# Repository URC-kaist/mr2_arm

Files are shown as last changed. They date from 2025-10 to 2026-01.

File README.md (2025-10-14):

# MR2 Arm Firmware

Firmware targeting the STM32H523 MCU that supervises two AS5600 magnetic encoders, a limit switch polled on GPIOA1, and broadcasts system state over classic CAN (FDCAN1). The code lives under `Core/Src/main.c` and is generated from STM32CubeMX, with custom logic in the `USER CODE` sections.

## High-Level Flow
- System clock configured to run from the CSI oscillator via PLL1 (SYSCLK ≈ 250 MHz).
- GPIO, I2C1/I2C2, ICACHE, FDCAN1, USART2, and TIM1 peripherals are initialized.
- FDCAN1 is started in normal classic-CAN mode and ready to transmit.
- TIM1 runs as a 10 Hz scheduler (prescaler 24 999, period 999). Its update interrupt raises `angle_check_pending` to request an encoder refresh.
- TIM2 runs as a 500 Hz poller for the limit switch and queues CAN updates.
- The main loop services queued limit-switch CAN events, executes encoder refresh work when requested, and idles via `__WFI()` when nothing is pending.

## Sensors and Peripherals

### AS5600 Encoders (I2C1 / I2C2)
- Each bus targets an AS5600 at 0x36 (7-bit address). Reads use `HAL_I2C_Mem_Read` from register `0x0E` (`ANGLE`).
- `AngleCheck_Run()` pulls the 12-bit angle from both sensors. Conversion to degrees is purely for UART logging; the broadcast value is kept in counts.
- Data is shifted to signed Q24 centered around mid-scale (`(angle - 2048) << 12`) and saturated to the ±24-bit range before being queued for CAN transmission.
- Each encoder publishes its own CAN frame (IDs `0x180` and `0x182` respectively); payload layout is detailed below.
- Encoder status flags track:
  - `bit0` (`ENC_FLAG_INDEX_SEEN`): at least one valid read has occurred.
  - `bit1` (`ENC_FLAG_ERROR_LATCHED`): a fault has been observed and latched.
  - `bit2` (`ENC_FLAG_SENSOR_FAULT`): latest read failed (cleared on the next good sample).
  - `bit3` (`ENC_FLAG_OVER_SPEED`): reserved for future use; never set in current code.
- I2C faults are logged to USART2 at 115 200 baud. After two consecutive failures the firmware attempts a soft bus recovery (deinit/re-init plus filter restore) before retrying the read once.

### Limit Switch (GPIOA Pin 1 / TIM2 sampled)
- TIM2 runs at 500 Hz in interrupt mode. Its period callback samples the GPIO and detects edges.
- The most recent state is broadcast immediately on any change and again every 200 ms (5 Hz) even if the level is unchanged.
- The timer ISR only prepares the CAN payload; the main loop performs the actual transmit when the TX FIFO has room.

### Scheduler (TIM1)
- With the configured prescaler and period, TIM1 Update fires every 100 ms.
- The callback increments `angle_check_pending`, allowing the main loop to run encoder polling at ~10 Hz.
- The initial call to `AngleCheck_Run()` ensures the encoders are read immediately after boot before the first timer tick.

### Serial Debug (USART2)
- Simple TX-only logging via `UART_SendLine()` for probe results and angle readouts.

## CAN Interface
Classic CAN (FDCAN1), 11-bit standard IDs, FD features disabled, no CRC inside the payloads (CAN handles CRC).

### 0x180 — Encoder 1 Status (sent every encoder poll)
| Bytes | Description |
|---|---|
| 0-2 | Encoder 1 position, signed Q24 big-endian (`PackS24BE`) |
| 3 | Encoder 1 status flags (`bit0 index_seen`, `bit1 error_latched`, `bit2 sensor_fault`, `bit3 over_speed`, others reserved) |
| 4-7 | Reserved (set to 0) |

### 0x182 — Encoder 2 Status (sent every encoder poll)
| Bytes | Description |
|---|---|
| 0-2 | Encoder 2 position, signed Q24 big-endian (`PackS24BE`) |
| 3 | Encoder 2 status flags (`bit0 index_seen`, `bit1 error_latched`, `bit2 sensor_fault`, `bit3 over_speed`, others reserved) |
| 4-7 | Reserved (set to 0) |

Notes (apply to both encoder status frames):
- Positions wrap naturally with the signed Q24 representation; receivers should apply their own counts-to-angle scaling using 4 096 counts per revolution.
- Fault bits remain latched until firmware reset; `sensor_fault` clears automatically on a good read.
- Although the code currently polls at 10 Hz, adjust `TIM1` prescaler/period if you require a 100 Hz cadence (update the README accordingly if you change it).

### 0x181 — Limit Switch State (5 Hz periodic, immediate on change)
| Bytes | Description |
|---|---|
| 0 | Switch state (`0` released, `1` pressed) |
| 1-7 | Reserved (set to 0) |

Notes:
- TIM2-driven sampling ensures new levels are observed within 2 ms. The firmware queues an out-of-band frame as soon as a change is detected, then resumes the 5 Hz cadence from that point.
- Frames are queued from the timer callback and emitted in the main loop; if the TX FIFO is full the entry is retried on the next pass.

## Extending the Firmware
- To add more diagnostics to CAN, reuse the helper `CAN_SendFrame()` and extend the payload tables above.
- Modify the `encoder_status_flags` logic to reflect any additional alarm conditions (e.g., overspeed detection) and document the bits here.
- If you retune the scheduler or switch to asynchronous encoder reads, ensure `LimitSwitch_Service()` still runs frequently enough to flush pending frames.

For detailed implementation, consult `Core/Src/main.c` (line numbers referenced above). Update this README whenever payload definitions or scheduling behavior change.

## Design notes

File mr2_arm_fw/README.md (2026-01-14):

# MR2 Arm Firmware

Firmware targeting the STM32H523 MCU that supervises two AS5600 magnetic encoders, dual-channel limit switches on GPIOA4–GPIOA7, and broadcasts system state over classic CAN (FDCAN1). CubeMX still owns the peripheral scaffolding in `Core/Src/main.c`, while the application logic now lives in:
- `Core/Src/app_encoder.c` — encoder sampling, I2C fault handling, and encoder CAN framing.
- `Core/Src/app_limit_switch.c` — limit switch polling, fault detection, and CAN framing.
- `Core/Src/app_can.c` — shared CAN helpers and bus-off recovery orchestration.
- `Core/Src/app_config.c` — holds runtime configuration that controls which
  channels are active and what CAN base ID to use.

## High-Level Flow
- System clock configured to run from the CSI oscillator via PLL1 (SYSCLK ≈ 250 MHz).
- GPIO, I2C1/I2C2, ICACHE, FDCAN1, USART2, and TIM1 peripherals are initialized.
- FDCAN1 is started in normal classic-CAN mode and ready to transmit.
- TIM1 runs as a 10 Hz scheduler (prescaler 24 999, period 999). Its update interrupt calls `AppEncoder_OnSchedulerTick()` to request a fresh encoder sample.
- TIM2 runs as a 500 Hz poller for the limit switches and invokes `AppLimitSwitch_Poll()` every tick.
- The main loop flushes queued limit-switch frames via `AppLimitSwitch_Service()`, performs encoder work via `AppEncoder_Service()`, services CAN bus-off recovery, and idles via `__WFI()` once nothing is pending.

## Sensors and Peripherals

### AS5600 Encoders (I2C1 / I2C2)
- Each bus targets an AS5600 at 0x36 (7-bit address). Reads use `HAL_I2C_Mem_Read` from register `0x0E` (`ANGLE`).
- `AppEncoder_Service()` performs the 12-bit angle read for both sensors when work is pending. Conversion to degrees is purely for UART logging; the broadcast value is kept in counts.
- Data is shifted to signed Q24 centered around mid-scale (`(angle - 2048) << 12`) and saturated to the ±24-bit range before being queued for CAN transmission.
- Each encoder publishes its own CAN frame (IDs `0x180` and `0x182` respectively); payload layout is detailed below.
- Encoder status flags track:
  - `bit0` (`ENC_FLAG_INDEX_SEEN`): at least one valid read has occurred.
  - `bit1` (`ENC_FLAG_ERROR_LATCHED`): a fault has been observed and latched.
  - `bit2` (`ENC_FLAG_SENSOR_FAULT`): latest read failed (cleared on the next good sample).
  - `bit3` (`ENC_FLAG_OVER_SPEED`): reserved for future use; never set in current code.
- I2C faults are logged to USART2 at 115 200 baud. After two consecutive failures the firmware attempts a soft bus recovery (deinit/re-init plus filter restore) before retrying the read once.

### Limit Switches (GPIOA Pins 4–7 / TIM2 sampled)
- SW1 and SW2 each provide normally-closed (NC) and normally-open (NO) contacts on pins `PA4`–`PA7`, sampled with `GPIO_PULLUP`.
- TIM2 runs at 500 Hz in interrupt mode. Its period callback reads all four contacts, detects changes, and records a change mask per switch via `AppLimitSwitch_Poll()`.
- For valid combinations (`NC=0, NO=1` = released, `NC=1, NO=0` = pressed) the firmware derives a binary state (`0` open, `1` closed) and clears the fault flag.
- Each switch publishes its status frame on its own CAN identifier immediately on any state or fault change, and otherwise every 200 ms (5 Hz) while the contacts remain valid.
- When an invalid combination is sampled (`NC == NO`), the frame's fault flag (`byte 1 bit 0`) is asserted and transmissions are rate-limited to once every 500 ms until the contacts return to a valid state (after which the cadence returns to 200 ms).
- The timer ISR only prepares the CAN payload; the main loop attempts the transmit in `AppLimitSwitch_Service()` when the TX FIFO has room.

### Scheduler (TIM1)
- With the configured prescaler and period, TIM1 Update fires every 100 ms.
- The callback defers to `AppEncoder_OnSchedulerTick()`, allowing the main loop to service encoder polling at ~10 Hz via `AppEncoder_Service()`.
- Startup logic requests and processes one encoder sample before the first timer tick so the CAN bus is primed immediately after boot.

### Debug Output (UART)
- `printf` is retargeted to `USART2` at 115 200 baud via `retarget.c`; all logs go out over that UART.

## CAN Interface
Classic CAN (FDCAN1), 11-bit standard IDs, FD features disabled, no CRC inside the payloads (CAN handles CRC).

### 0x180 — Encoder 1 Status (sent every encoder poll, 4-byte DLC)
| Bytes | Description |
|---|---|
| 0-2 | Encoder 1 position, signed Q24 big-endian (`PackS24BE`) |
| 3 | Encoder 1 status flags (`bit0 index_seen`, `bit1 error_latched`, `bit2 sensor_fault`, `bit3 over_speed`, others reserved) |

### 0x182 — Encoder 2 Status (sent every encoder poll, 4-byte DLC)
| Bytes | Description |
|---|---|
| 0-2 | Encoder 2 position, signed Q24 big-endian (`PackS24BE`) |
| 3 | Encoder 2 status flags (`bit0 index_seen`, `bit1 error_latched`, `bit2 sensor_fault`, `bit3 over_speed`, others reserved) |

Notes (apply to both encoder status frames):
- Positions wrap naturally with the signed Q24 representation; receivers should apply their own counts-to-angle scaling using 4 096 counts per revolution. With the reduced DLC, only bytes 0–3 are emitted (no padding).
- Fault bits remain latched until firmware reset; `sensor_fault` clears automatically on a good read.
- Although the code currently polls at 10 Hz, adjust `TIM1` prescaler/period if you require a 100 Hz cadence (update the README accordingly if you change it).

### 0x181 — Limit Switch 1 Status (SW1, immediate on change; 5 Hz valid / 0.5 s fault cadence, 2-byte DLC)
| Bytes | Description |
|---|---|
| 0 | Switch state (`0` open, `1` closed). When a fault is active the last known state is retained. |
| 1 | Fault bits (`bit0`=1 when NC/NO inputs disagree; other bits reserved 0). |

### 0x183 — Limit Switch 2 Status (SW2, immediate on change; 5 Hz valid / 0.5 s fault cadence, 2-byte DLC)
| Bytes | Description |
|---|---|
| 0 | Switch state (`0` open, `1` closed). When a fault is active the last known state is retained. |
| 1 | Fault bits (`bit0`=1 when NC/NO inputs disagree; other bits reserved 0). |

Notes:
- TIM2-driven sampling ensures new levels are observed within 2 ms. The firmware queues an out-of-band frame as soon as a state or fault change is detected.

- While the contacts remain valid, status frames repeat every 200 ms. When a fault persists, transmissions are throttled to once every 500 ms until the inputs recover.
- Frames are queued from the timer callback and emitted in the main loop; if the TX FIFO is full the latest payload is retried on the next pass.

### Runtime Configuration (`AppConfig`)
- The `AppConfig` struct enables or disables each sensor independently (`enable_sw1`, `enable_sw2`, `enable_encoder1`, `enable_encoder2`). Disabled channels neither sample hardware nor emit CAN frames.
- You can supply explicit 11-bit CAN IDs per channel via `can_id_encoder1`, `can_id_encoder2`, `can_id_sw1`, `can_id_sw2` (set to `0` to fall back to the base+offset scheme). All IDs must be ≤ `0x7FF`.
- If no per-channel ID is provided, `can_base_id` sets the starting standard ID for all status frames (default `0x180`). Offsets are fixed: encoder1 = `base+0`, SW1 = `base+1`, encoder2 = `base+2`, SW2 = `base+3`. `can_base_id` values above `0x7FC` are rejected to keep offsets within the 11-bit range.
- Defaults are applied in `main.c` via `AppConfig_InitDefaults()`/`AppConfig_Set()`, then pushed into the modules with `AppEncoder_ApplyConfig()` and `AppLimitSwitch_ApplyConfig()`. Replace or extend this block to load setup data from DIP switches, flash, or a higher-level setup routine.

## Extending the Firmware
- To add more diagnostics to CAN, reuse the helper `AppCAN_SendFrame()` and extend the payload tables above.
- Modify the encoder module (`app_encoder.c`) to reflect any additional alarm conditions (e.g., overspeed detection) and document the bits here.
- If you retune the scheduler or switch to asynchronous encoder reads, ensure `AppLimitSwitch_Service()` still runs frequently enough to flush pending frames.

For detailed implementation, refer to the module sources listed above. Update this README whenever payload definitions, scheduling behavior, or module responsibilities change.

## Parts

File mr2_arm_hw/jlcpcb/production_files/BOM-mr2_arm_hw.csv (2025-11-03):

Comment | Designator | Footprint | LCSC | Quantity
100n | C10,C11,C12,C13,C14,C15,C17,C4,C6 | C_0402_1005Metric | C77020 | 9
100u | C1 | CP_Elec_10x12.5 | C22387799 | 1
10k | R2,R7,R8,R9 | C_0402_1005Metric | C60490 | 4
10p | C18,C19 | C_0402_1005Metric | C782046 | 2
10u | C2,C3 | C_1210_3225Metric | C5156756 | 2
10u | C7,C8 | C_0603_1608Metric | C96446 | 2
15u | L1 | L_Changjiang_FNR4020S | C167837 | 1
1N4148 | D1 | D_SOD-323 | C129905 | 1
1u | C16,C5,C9 | C_0603_1608Metric | C14663 | 3
2k2 | R3,R4,R5,R6 | C_0402_1005Metric | C25879 | 4
2u2 | C20,C21 | C_0402_1005Metric | C170151 | 2
31k2 | R1 | C_0402_1005Metric | C11463 | 1
600Ω @ 100MHz | FB1 | C_0603_1608Metric | C19330 | 1
B1100 | D2 | D_SMA | C2848680 | 1
BOOT0 | SW2 | SW_Push_1P1T_NO_CK_KMR2 | C221678 | 1
MCP16331x-xCH | U1 | SOT-23-6 | C105695 | 1
NRST | SW1 | SW_Push_1P1T_NO_CK_KMR2 | C221678 | 1
SN65HVD230 | U2 | SOIC-8_3.9x4.9mm_P1.27mm | C16468 | 1
STM32H523CETx | U3 | LQFP-48_7x7mm_P0.5mm | C22460834 | 1
X322516MLB4SI | Y1 | Crystal_SMD_3225-4Pin_3.2x2.5mm | C13738 | 1
USART2 | J2 | Molex_SPOX_5268-04A_1x04_P2.50mm_Horizontal |  | 1
I2C2 | J4 | Molex_SPOX_5268-04A_1x04_P2.50mm_Horizontal |  | 1
SW2 | J6 | Molex_SPOX_5268-03A_1x03_P2.50mm_Horizontal |  | 1
XT30PW(2+2)-M.G.B | U4 | CONN-TH_4P-XT30PW-M |  | 1
SW1 | J5 | Molex_SPOX_5268-03A_1x03_P2.50mm_Horizontal |  | 1
I2C1 | J3 | Molex_SPOX_5268-04A_1x04_P2.50mm_Horizontal |  | 1

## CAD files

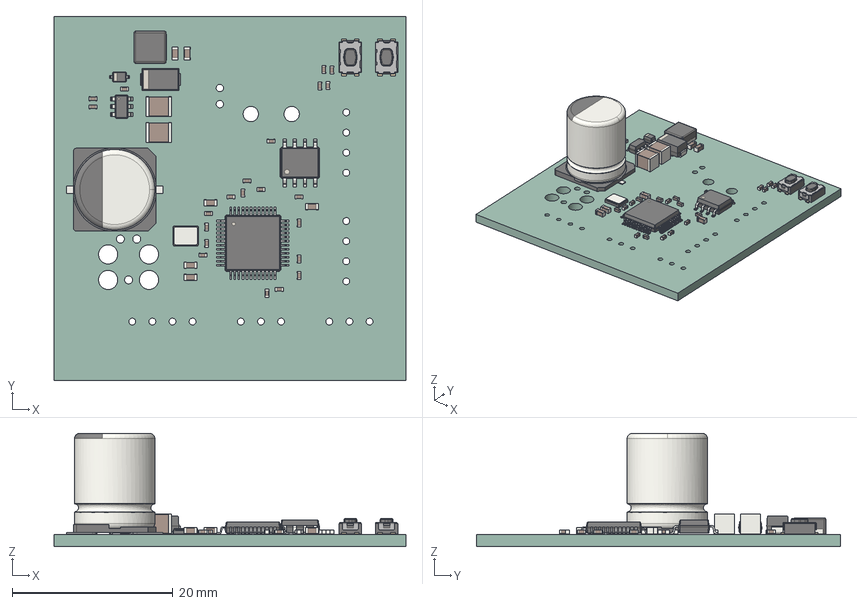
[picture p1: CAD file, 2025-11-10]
mr2_arm_hw/mr2_arm_hw.step
43.7 x 45.2 x 14.1 mm
C_0402_1005Metric x 22
C_0603_1608Metric x 6
Crystal_SMD_3225-4Pin_3.2x2.5mm
C_1210_3225Metric x 2
CP_Elec_10x12.5
SW_Push_1P1T_NO_CK_KMR2 x 2
L_Changjiang_FNR4020S
SOIC-8_3.9x4.9mm_P1.27mm
SOT-23-6
D_SOD-323
D_SMA
LQFP-48_7x7mm_P0.5mm
mr2_arm_hw_PCB

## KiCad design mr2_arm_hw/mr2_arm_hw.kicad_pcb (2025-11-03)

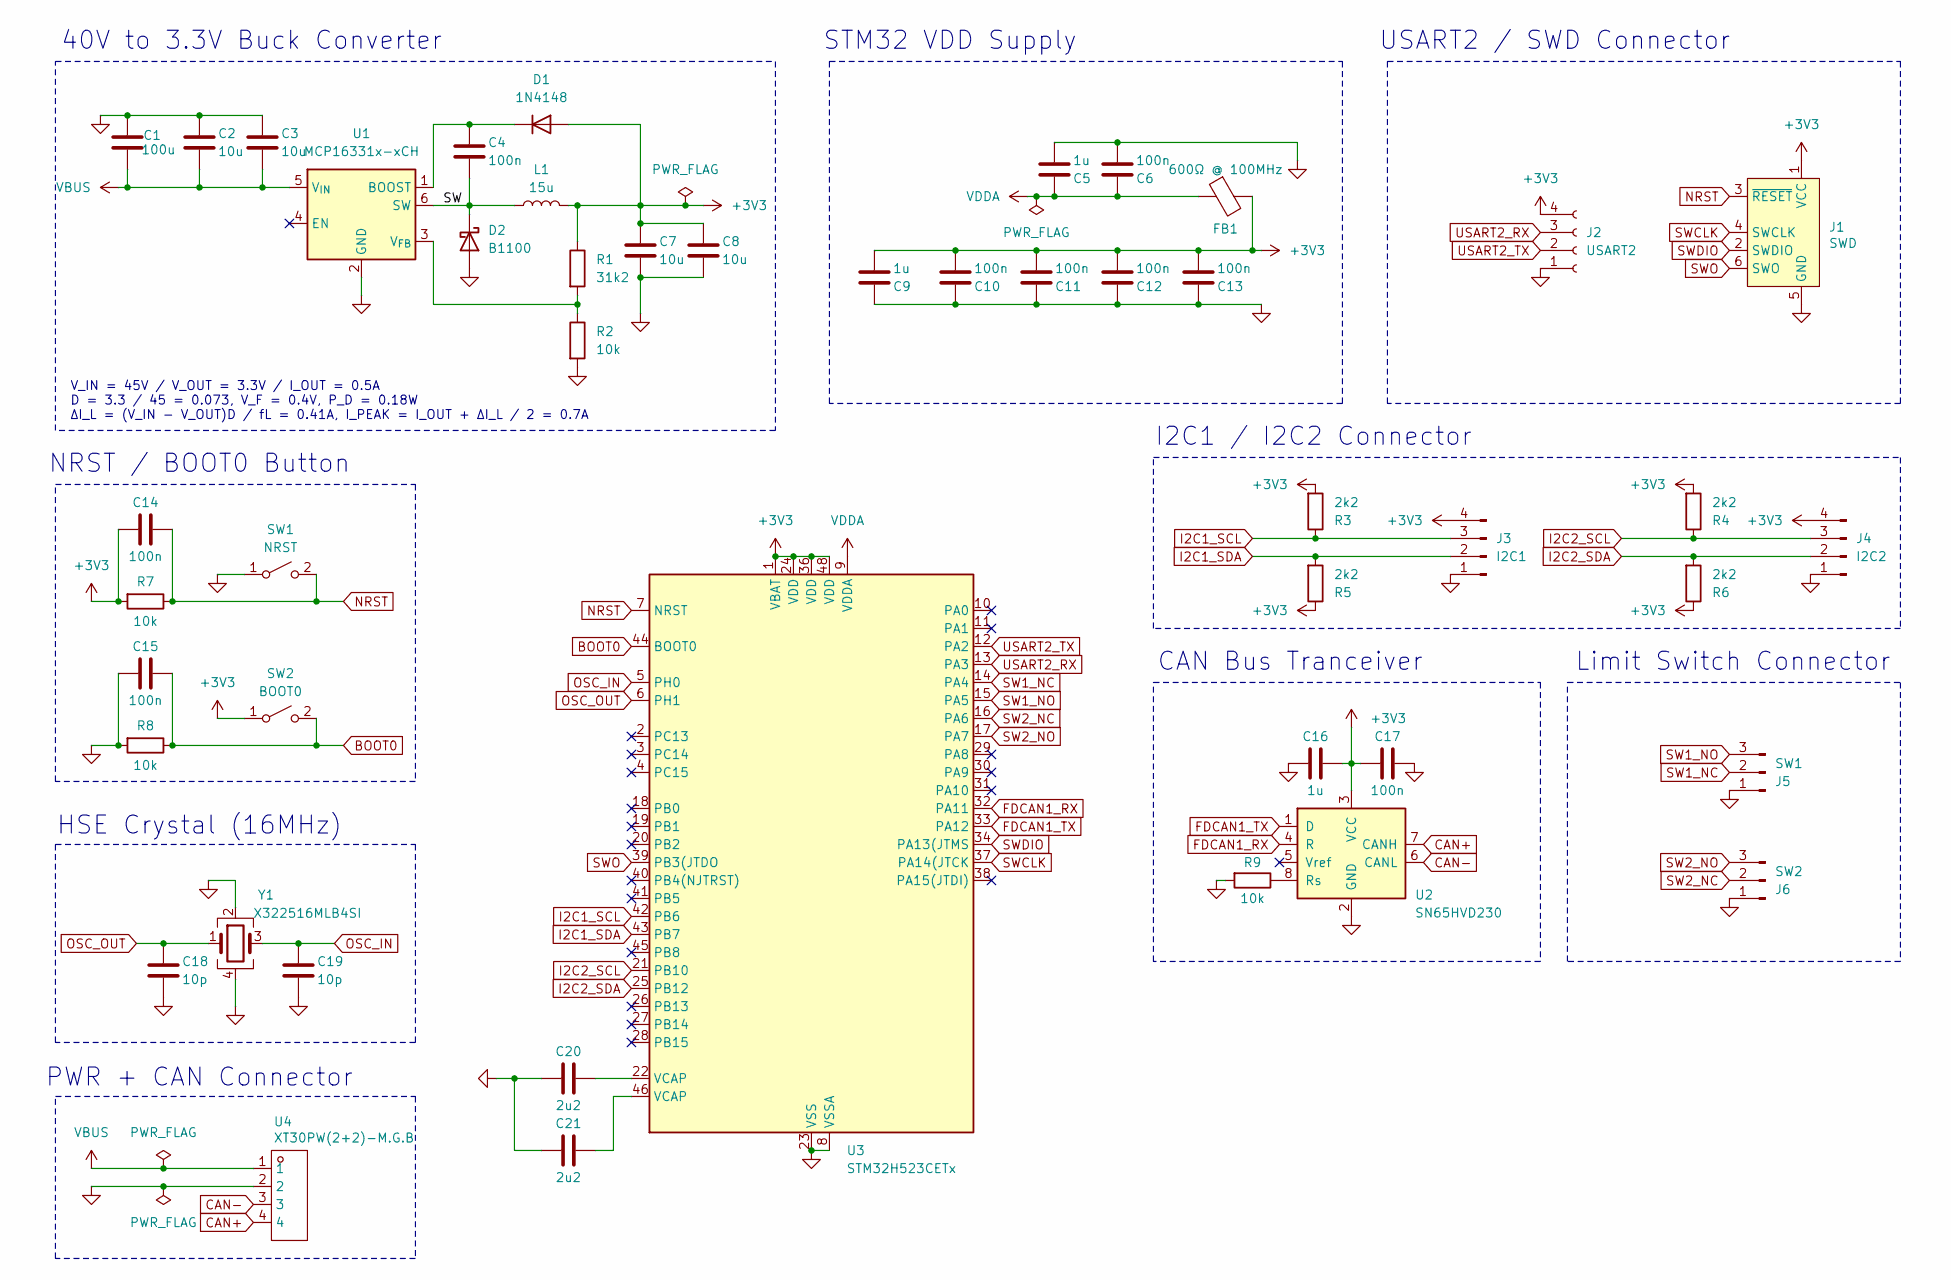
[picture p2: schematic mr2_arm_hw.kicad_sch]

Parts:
C1: 100u; CP_Elec_10x12.5
C2, C3: 10u; C_1210_3225Metric
C4, C6, C10, C11, C12, C13, C14, C15, C17: 100n; C_0402_1005Metric
C5, C9, C16: 1u; C_0603_1608Metric
C7, C8: 10u; C_0603_1608Metric
C18, C19: 10p; C_0402_1005Metric
C20, C21: 2u2; C_0402_1005Metric
D1: 1N4148; D_SOD-323
D2: B1100; D_SMA
FB1: 600Ω @ 100MHz; C_0603_1608Metric
J1: SWD; Tag-Connect_TC2030-IDC-FP_2x03_P1.27mm_Vertical
J2: USART2; Molex_SPOX_5268-04A_1x04_P2.50mm_Horizontal
J3: I2C1; Molex_SPOX_5268-04A_1x04_P2.50mm_Horizontal
J4: I2C2; Molex_SPOX_5268-04A_1x04_P2.50mm_Horizontal
J5: SW1; Molex_SPOX_5268-03A_1x03_P2.50mm_Horizontal
J6: SW2; Molex_SPOX_5268-03A_1x03_P2.50mm_Horizontal
L1: 15u; L_Changjiang_FNR4020S
R1: 31k2; C_0402_1005Metric
R2, R7, R8, R9: 10k; C_0402_1005Metric
R3, R4, R5, R6: 2k2; C_0402_1005Metric
SW1: NRST; SW_Push_1P1T_NO_CK_KMR2
SW2: BOOT0; SW_Push_1P1T_NO_CK_KMR2
U1: MCP16331x-xCH; SOT-23-6
U2: SN65HVD230; SOIC-8_3.9x4.9mm_P1.27mm
U3: STM32H523CETx; LQFP-48_7x7mm_P0.5mm
U4: XT30PW(2+2)-M.G.B; CONN-TH_4P-XT30PW-M; Manufacturer Part XT30PW(2+2)-M.G.B; LCSC Part Name XT30PW(2+2)功率数据混合插头公金黑PCB弯插
Y1: X322516MLB4SI; Crystal_SMD_3225-4Pin_3.2x2.5mm

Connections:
+3V3: C7.1, C8.1, C9.2, C10.2, C11.2, C12.2, C13.2, C14.1, C16.2, C17.1, D1.2 (A), FB1.2, J1.1 (VCC), J2.4, J3.4, J4.4, L1.2, R1.1, R3.2, R4.2, R5.1, R6.1, R7.2, SW2.1 (A), U2.3 (VCC), U3.1 (VBAT), U3.24 (VDD), U3.36 (VDD), U3.48 (VDD)
/<NO NET>: C4.2, D2.1 (K), L1.1, U1.6 (SW)
BOOT0: C15.2, R8.1, SW2.2 (B), U3.44 (BOOT0)
CAN+: U2.7 (CANH), U4.4
CAN-: U2.6 (CANL), U4.3
FDCAN1_RX: U2.4 (R), U3.32 (PA11)
FDCAN1_TX: U2.1 (D), U3.33 (PA12)
GND: C1.2, C2.1, C3.1, C5.2, C6.2, C7.2, C8.2, C9.1, C10.1, C11.1, C12.1, C13.1, C15.1, C16.1, C17.2, C18.2, C19.2, C20.1, C21.1, D2.2 (A), J1.5 (GND), J2.1, J3.1, J4.1, J5.1, J6.1, R2.2, R8.2, R9.2, SW1.1 (A), U1.2 (GND), U2.2 (GND), U3.8 (VSSA), U3.23 (VSS), U3.35 (VSS), U3.47 (VSS), U4.2, Y1.2, Y1.4
I2C1_SCL: J3.3, R3.1, U3.42 (PB6)
I2C1_SDA: J3.2, R5.2, U3.43 (PB7)
I2C2_SCL: J4.3, R4.1, U3.21 (PB10)
I2C2_SDA: J4.2, R6.2, U3.25 (PB12)
NRST: C14.2, J1.3 (~RESET), R7.1, SW1.2 (B), U3.7 (NRST)
unnamed: C20.2, U3.22 (VCAP)
unnamed: C21.2, U3.46 (VCAP)
unnamed: C4.1, D1.1 (K), U1.1 (BOOST)
unnamed: R1.2, R2.1, U1.3 (V_{FB})
unnamed: R9.1, U2.8 (Rs)
OSC_IN: C19.1, U3.5 (PH0), Y1.3
OSC_OUT: C18.1, U3.6 (PH1), Y1.1
SW1_NC: J5.2, U3.14 (PA4)
SW1_NO: J5.3, U3.15 (PA5)
SW2_NC: J6.2, U3.16 (PA6)
SW2_NO: J6.3, U3.17 (PA7)
SWCLK: J1.4 (SWCLK), U3.37 (PA14(JTCK)
SWDIO: J1.2 (SWDIO), U3.34 (PA13(JTMS)
SWO: J1.6 (SWO), U3.39 (PB3(JTDO)
USART2_RX: J2.3, U3.13 (PA3)
USART2_TX: J2.2, U3.12 (PA2)
VBUS: C1.1, C2.2, C3.2, U1.5 (V_{IN}), U4.1
VDDA: C5.1, C6.1, FB1.1, U3.9 (VDDA)

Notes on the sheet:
V_IN = 45V / V_OUT = 3.3V / I_OUT = 0.5A D = 3.3 / 45 = 0.073, V_F = 0.4V, P_D = 0.18W ΔI_L = (V_IN - V_OUT)D / fL = 0.41A, I_PEAK = I_OUT + ΔI_L / 2 = 0.7A
40V to 3.3V Buck Converter
CAN Bus Tranceiver
Limit Switch Connector
STM32 VDD Supply
HSE Crystal (16MHz)
NRST / BOOT0 Button
I2C1 / I2C2 Connector
PWR + CAN Connector
USART2 / SWD Connector

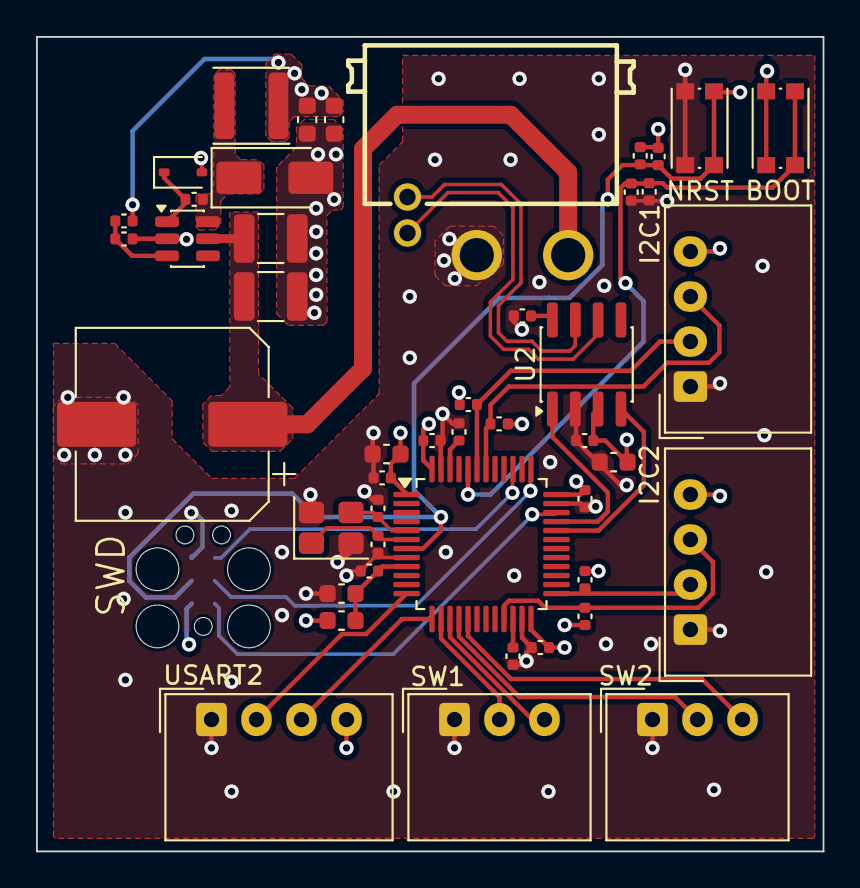
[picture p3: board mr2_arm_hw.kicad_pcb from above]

Board: 4 copper layers, 43.7 x 45.2 mm, 47 parts (1 on the bottom side), 31 nets.

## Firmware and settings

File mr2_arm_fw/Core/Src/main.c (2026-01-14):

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
/* Includes ------------------------------------------------------------------*/
#include "main.h"

/* USER CODE BEGIN Includes */
#include "app_can.h"
#include "app_config.h"
#include "app_encoder.h"
#include "app_limit_switch.h"
#include <stdio.h>
/* USER CODE END Includes */


FDCAN_HandleTypeDef hfdcan1;

I2C_HandleTypeDef hi2c1;
I2C_HandleTypeDef hi2c2;

TIM_HandleTypeDef htim1;
TIM_HandleTypeDef htim2;

UART_HandleTypeDef huart2;

/* USER CODE BEGIN PV */
static AppConfig g_app_config;
/* USER CODE END PV */

void SystemClock_Config(void);
static void MX_GPIO_Init(void);
static void MX_I2C1_Init(void);
static void MX_I2C2_Init(void);
static void MX_ICACHE_Init(void);
static void MX_FDCAN1_Init(void);
static void MX_USART2_UART_Init(void);
static void MX_TIM1_Init(void);
static void MX_TIM2_Init(void);
/* USER CODE BEGIN 0 */
/* Expose a non-generated FDCAN reinit entry point for app_can.c */
void App_FDCAN1_Reinit(void) { MX_FDCAN1_Init(); }
/* USER CODE END 0 */

/**
 * @brief  The application entry point.
 * @retval int
 */
int main(void) {

  /* MCU Configuration--------------------------------------------------------*/

  /* Reset of all peripherals, Initializes the Flash interface and the Systick.
   */
  HAL_Init();

  /* USER CODE BEGIN Init */

  printf("Starting board!\n");

  /* Populate runtime config (defaults for now; extend to load from NVM or
   * DIP switches as needed). */
  AppConfig_InitDefaults(&g_app_config);
  /* Requested setup: SW1 on ID 204, Encoder1 on ID 205,
   * SW2 on ID 206; Encoder2 left disabled. */
  g_app_config.enable_sw1 = 1u;
  g_app_config.enable_encoder1 = 1u;
  g_app_config.enable_sw2 = 1u;
  g_app_config.enable_encoder2 = 0u;
  g_app_config.can_id_sw1 = 204u;
  g_app_config.can_id_encoder1 = 205u;
  g_app_config.can_id_sw2 = 206u;
  g_app_config.can_id_encoder2 = 0u;
  (void)AppConfig_Set(&g_app_config);

  /* USER CODE END Init */

  /* Configure the system clock */
  SystemClock_Config();

  /* Initialize all configured peripherals */
  MX_GPIO_Init();
  MX_I2C1_Init();
  MX_I2C2_Init();
  MX_ICACHE_Init();
  MX_FDCAN1_Init();
  MX_USART2_UART_Init();
  MX_TIM1_Init();
  MX_TIM2_Init();
  /* USER CODE BEGIN 2 */
  AppCAN_Init();
  AppEncoder_Init();
  AppLimitSwitch_Init();
  AppEncoder_ApplyConfig(AppConfig_Get());
  AppLimitSwitch_ApplyConfig(AppConfig_Get());
  if (HAL_FDCAN_ActivateNotification(&hfdcan1, FDCAN_IT_BUS_OFF, 0U) !=
      HAL_OK) {
    Error_Handler();
  }
  if (HAL_FDCAN_Start(&hfdcan1) != HAL_OK) {
    Error_Handler();
  }
  if (HAL_TIM_Base_Start_IT(&htim1) != HAL_OK) {
    Error_Handler();
  }
  if (HAL_TIM_Base_Start_IT(&htim2) != HAL_OK) {
    Error_Handler();
  }
  AppEncoder_RequestMeasurement();
  (void)AppEncoder_Service();
  AppCAN_ServiceBusOff();
  AppLimitSwitch_Poll();
  /* USER CODE END 2 */

  /* Infinite loop */
  /* USER CODE BEGIN WHILE */
  while (1) {
    /* USER CODE END WHILE */

    /* USER CODE BEGIN 3 */
    AppLimitSwitch_Service();
    AppCAN_ServiceBusOff();

    if (AppEncoder_Service()) {
      AppCAN_ServiceBusOff();
      continue;
    }

    if (AppLimitSwitch_HasPending()) {
      continue;
    }

    __WFI();
  }
  /* USER CODE END 3 */
}

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
/* USER CODE BEGIN 4 */
void HAL_TIM_PeriodElapsedCallback(TIM_HandleTypeDef *htim) {
  if (htim->Instance == TIM1) {
    AppEncoder_OnSchedulerTick();
  } else if (htim->Instance == TIM2) {
    AppLimitSwitch_Poll();
  }
}

void HAL_FDCAN_ErrorStatusCallback(FDCAN_HandleTypeDef *hfdcan,
                                   uint32_t ErrorStatusITs) {
  if (hfdcan == &hfdcan1) {
    AppCAN_HandleErrorStatus(ErrorStatusITs);
  }
}

/* USER CODE END 4 */
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


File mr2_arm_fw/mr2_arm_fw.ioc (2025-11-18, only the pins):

Mcu.UserName=STM32H523CETx
PA11.Signal=FDCAN1_RX
PA12.Signal=FDCAN1_TX
PA13(JTMS/SWDIO).Signal=DEBUG_JTMS-SWDIO
PA14(JTCK/SWCLK).Signal=DEBUG_JTCK-SWCLK
PA2.Signal=USART2_TX
PA3.Signal=USART2_RX
PA4.GPIO_Label=SW1_NC
PA4.Signal=GPIO_Input
PA5.GPIO_Label=SW1_NO
PA5.Signal=GPIO_Input
PA6.GPIO_Label=SW2_NC
PA6.Signal=GPIO_Input
PA7.GPIO_Label=SW2_NO
PA7.Signal=GPIO_Input
PB10.Signal=I2C2_SCL
PB12.Signal=I2C2_SDA
PB3(JTDO/TRACESWO).Signal=DEBUG_JTDO-SWO
PB6.Signal=I2C1_SCL
PB7.Signal=I2C1_SDA
PH0-OSC_IN(PH0).Signal=RCC_OSC_IN
PH1-OSC_OUT(PH1).Signal=RCC_OSC_OUT

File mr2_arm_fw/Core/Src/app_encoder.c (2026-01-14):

#include "app_encoder.h"

#include <stddef.h>
#include <stdint.h>
#include <stdio.h>

#include "app_can.h"
#include "app_config.h"

#define AS5600_I2C_ADDR (0x36u << 1)
#define AS5600_ANGLE_START 0x0Eu
#define AS5600_STEPS 4096.0f
#define CAN_ID_ENCODER_BASE_DEFAULT 0x180U
#define ENC_FLAG_INDEX_SEEN 0x01u
#define ENC_FLAG_ERROR_LATCHED 0x02u
#define ENC_FLAG_SENSOR_FAULT 0x04u
#define ENC_FLAG_OVER_SPEED 0x08u
#define I2C_FAULT_RECOVERY_THRESHOLD 2u

typedef struct {
  I2C_HandleTypeDef *handle;
  const char *name;
  uint32_t consecutive_failures;
} I2C_FaultContext;

extern I2C_HandleTypeDef hi2c1;
extern I2C_HandleTypeDef hi2c2;

static FDCAN_TxHeaderTypeDef encoder_headers[2];
static uint8_t encoder_status_flags[2] = {0u, 0u};
static int32_t encoder_position_q24[2] = {0};
static volatile uint32_t angle_check_pending = 0UL;
static uint8_t encoder_enabled[2] = {1u, 1u};
static uint16_t encoder_can_base_id = CAN_ID_ENCODER_BASE_DEFAULT;
static I2C_FaultContext i2c_fault_contexts[] = {
    {&hi2c1, "I2C1", 0u},
    {&hi2c2, "I2C2", 0u},
};

static int32_t ClampToS24(int32_t value);
static void PackS24BE(uint8_t *dest, int32_t value);
static HAL_StatusTypeDef AS5600_ReadAngle12(I2C_HandleTypeDef *hi2c,
                                            uint16_t *angle12);
static void print_i2c_error(const char *tag, I2C_HandleTypeDef *hi2c);
static HAL_StatusTypeDef probe_as5600(I2C_HandleTypeDef *hi2c,
                                      const char *tag);
static I2C_FaultContext *I2C_GetContext(I2C_HandleTypeDef *handle);
static HAL_StatusTypeDef I2C_RecoverBus(I2C_FaultContext *ctx);
static HAL_StatusTypeDef I2C_HandleFault(I2C_FaultContext *ctx);
static HAL_StatusTypeDef AS5600_ReadAngleWithFallback(I2C_HandleTypeDef *hi2c,
                                                      I2C_FaultContext *ctx,
                                                      uint16_t *angle12);
static void AppEncoder_RunSample(void);
static void AppEncoder_SendStatus(uint8_t index);
static void AppEncoder_OnBusReset(void);
static void AppEncoder_RefreshHeaders(void);
static uint8_t AppEncoder_ChannelEnabled(uint8_t index);
static uint32_t AppEncoder_GetId(uint8_t index);

void AppEncoder_Init(void) {
  angle_check_pending = 0UL;
  for (size_t i = 0;
       i < (sizeof(i2c_fault_contexts) / sizeof(i2c_fault_contexts[0])); ++i) {
    i2c_fault_contexts[i].consecutive_failures = 0u;
  }
  encoder_status_flags[0] = 0u;
  encoder_status_flags[1] = 0u;
  encoder_position_q24[0] = 0;
  encoder_position_q24[1] = 0;
  encoder_enabled[0] = 1u;
  encoder_enabled[1] = 1u;
  encoder_can_base_id = CAN_ID_ENCODER_BASE_DEFAULT;
  AppEncoder_RefreshHeaders();
  AppCAN_RegisterBusResetCallback(AppEncoder_OnBusReset);
}

void AppEncoder_ApplyConfig(const AppConfig *cfg) {
  if (cfg == NULL) {
    return;
  }

  encoder_enabled[0] = (cfg->enable_encoder1 != 0u) ? 1u : 0u;
  encoder_enabled[1] = (cfg->enable_encoder2 != 0u) ? 1u : 0u;

  if (cfg->can_base_id <= 0x7FCu) {
    encoder_can_base_id = cfg->can_base_id;
  }
  if (cfg->can_id_encoder1 != 0u) {
    encoder_headers[0].Identifier = cfg->can_id_encoder1;
  }
  if (cfg->can_id_encoder2 != 0u) {
    encoder_headers[1].Identifier = cfg->can_id_encoder2;
  }

  if ((encoder_enabled[0] == 0u) && (encoder_enabled[1] == 0u)) {
    angle_check_pending = 0UL;
  }

  AppEncoder_RefreshHeaders();
}

void AppEncoder_RequestMeasurement(void) {
  if ((encoder_enabled[0] == 0u) && (encoder_enabled[1] == 0u)) {
    return;
  }
  if (angle_check_pending < UINT32_MAX) {
    angle_check_pending++;
  }
}

void AppEncoder_OnSchedulerTick(void) { AppEncoder_RequestMeasurement(); }

bool AppEncoder_Service(void) {
  if (angle_check_pending == 0UL) {
    return false;
  }
  angle_check_pending--;
  AppEncoder_RunSample();
  return true;
}

static void AppEncoder_OnBusReset(void) {
  AppEncoder_RefreshHeaders();
  AppEncoder_SendStatus(0U);
  AppEncoder_SendStatus(1U);
}

static HAL_StatusTypeDef AS5600_ReadAngle12(I2C_HandleTypeDef *hi2c,
                                            uint16_t *angle12) {
  if ((hi2c == NULL) || (angle12 == NULL)) {
    return HAL_ERROR;
  }

  uint8_t buf[2] = {0};
  HAL_StatusTypeDef st =
      HAL_I2C_Mem_Read(hi2c, AS5600_I2C_ADDR, AS5600_ANGLE_START,
                       I2C_MEMADD_SIZE_8BIT, buf, sizeof(buf), 10);
  if (st != HAL_OK) {
    return st;
  }

  *angle12 = (uint16_t)(((buf[0] & 0x0Fu) << 8) | buf[1]);
  return HAL_OK;
}

static void print_i2c_error(const char *tag, I2C_HandleTypeDef *hi2c) {
  uint32_t err = HAL_I2C_GetError(hi2c);
  printf("%s ERR=0x%08lX%s%s%s%s%s%s\r\n", tag, (unsigned long)err,
         (err & HAL_I2C_ERROR_BERR) ? " BERR" : "",
         (err & HAL_I2C_ERROR_ARLO) ? " ARLO" : "",
         (err & HAL_I2C_ERROR_AF) ? " AF(NACK)" : "",
         (err & HAL_I2C_ERROR_OVR) ? " OVR" : "",
         (err & HAL_I2C_ERROR_DMA) ? " DMA" : "",
         (err & HAL_I2C_ERROR_TIMEOUT) ? " TIMEOUT" : "");
}

static HAL_StatusTypeDef probe_as5600(I2C_HandleTypeDef *hi2c,
                                      const char *tag) {
  HAL_StatusTypeDef st = HAL_I2C_IsDeviceReady(hi2c, AS5600_I2C_ADDR, 3, 10);
  if (st != HAL_OK) {
    printf("%s: NACK @0x36\r\n", tag);
    print_i2c_error(tag, hi2c);
  } else {
    printf("%s: OK\r\n", tag);
  }
  return st;
}

static int32_t ClampToS24(int32_t value) {
  if (value > 0x7FFFFF) {
    return 0x7FFFFF;
  }
  if (value < -0x800000) {
    return -0x800000;
  }
  return value;
}

static void PackS24BE(uint8_t *dest, int32_t value) {
  const int32_t clamped = ClampToS24(value);
  dest[0] = (uint8_t)((uint32_t)clamped >> 16);
  dest[1] = (uint8_t)((uint32_t)clamped >> 8);
  dest[2] = (uint8_t)((uint32_t)clamped);
}

static I2C_FaultContext *I2C_GetContext(I2C_HandleTypeDef *handle) {
  if (handle == NULL) {
    return NULL;
  }
  for (size_t i = 0;
       i < (sizeof(i2c_fault_contexts) / sizeof(i2c_fault_contexts[0])); ++i) {
    if (i2c_fault_contexts[i].handle == handle) {
      return &i2c_fault_contexts[i];
    }
  }
  return NULL;
}

static HAL_StatusTypeDef I2C_RecoverBus(I2C_FaultContext *ctx) {
  if (ctx == NULL) {
    return HAL_ERROR;
  }

  if (HAL_I2C_DeInit(ctx->handle) != HAL_OK) {
    printf("%s: I2C deinit failed\r\n", ctx->name);
    return HAL_ERROR;
  }

  if (HAL_I2C_Init(ctx->handle) != HAL_OK) {
    printf("%s: I2C init failed\r\n", ctx->name);
    return HAL_ERROR;
  }

  if (HAL_I2CEx_ConfigAnalogFilter(ctx->handle, I2C_ANALOGFILTER_ENABLE) !=
      HAL_OK) {
    printf("%s: analog filter cfg failed\r\n", ctx->name);
    return HAL_ERROR;
  }

  if (HAL_I2CEx_ConfigDigitalFilter(ctx->handle, 0) != HAL_OK) {
    printf("%s: digital filter cfg failed\r\n", ctx->name);
    return HAL_ERROR;
  }

  return HAL_OK;
}
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

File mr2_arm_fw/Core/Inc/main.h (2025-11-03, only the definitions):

#define SW1_NC_Pin GPIO_PIN_4
#define SW1_NC_GPIO_Port GPIOA
#define SW1_NO_Pin GPIO_PIN_5
#define SW1_NO_GPIO_Port GPIOA
#define SW2_NC_Pin GPIO_PIN_6
#define SW2_NC_GPIO_Port GPIOA
#define SW2_NO_Pin GPIO_PIN_7
#define SW2_NO_GPIO_Port GPIOA

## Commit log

2025-10-13 Split encoder CAN status frames
2025-10-13 fix flaky can dhutdowns
    [main.c, mr2_arm_fw.ioc]
2025-10-14 Refactor limit switch handling and add TIM2 polling
2025-11-03 integrate hw and fw file
    [BOM-mr2_arm_hw.csv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]
2025-11-10 Add CAN helpers and latest hardware backups
    [mr2_arm_hw.step]

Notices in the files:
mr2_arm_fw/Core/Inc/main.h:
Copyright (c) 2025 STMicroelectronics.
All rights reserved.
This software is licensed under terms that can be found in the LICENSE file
